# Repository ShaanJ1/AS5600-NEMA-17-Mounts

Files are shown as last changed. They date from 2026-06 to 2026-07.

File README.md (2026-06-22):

# AS5600 Nema 17 Mounts

Mounting hardware for attaching the AS5600 rotary encoder onto the back of the NEMA 17 stepper motor
Includes a magnet centering jig which helps you properly center the magnet onto the rear shaft to glue it in place

## Mounting Options:
### 1. Custom PCB + Spacers
Parts required:
- Diametric magnet
- Super glue (or equivalent strong adhesive)
- 4x M3 Machine Screws
- Custom AS5600 breakout board
- 4x Spacers

Installation Steps:

### 2. Custom mount for the AS5600
Parts Required:
- Diametric magnet
- Super glue (or equivalent strong adhesive)
- 3D printed sensor housing
- Regular AS5600 PCB
- 4x M2.5 screws

Installation Steps:

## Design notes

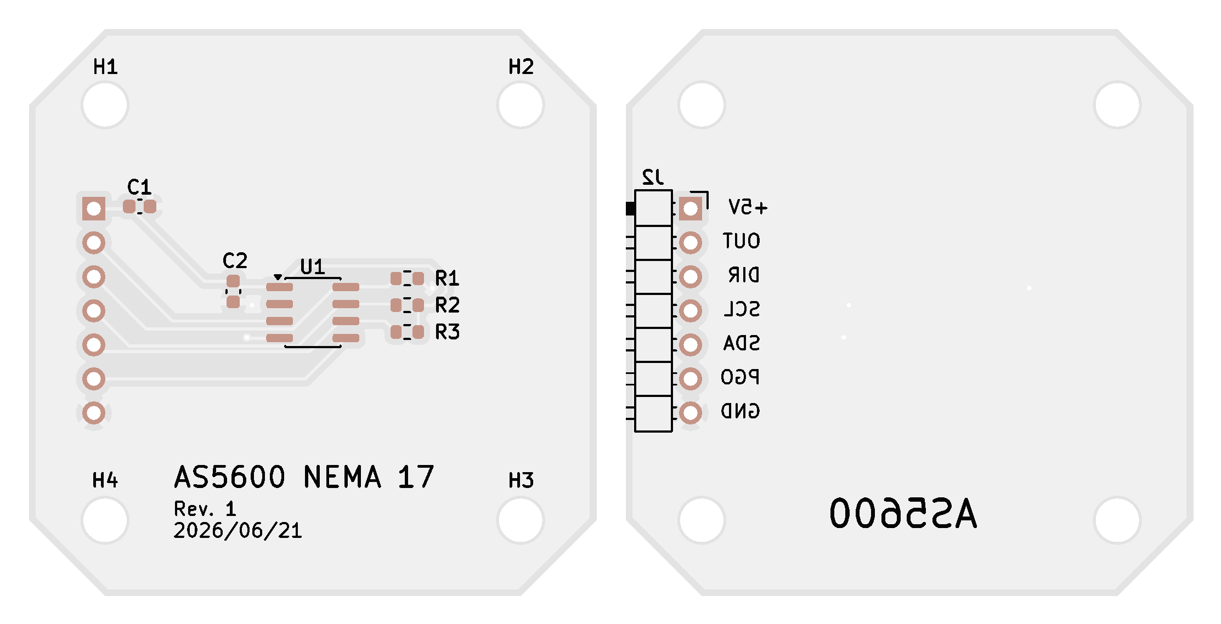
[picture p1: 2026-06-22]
pcb.png

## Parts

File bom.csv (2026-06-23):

Item Name/Purpose | Product Number | URL | Price | Quantity | Designator | Note
0.1uF 0603 Capacitor | C0603C104K3RACTU | https://www.digikey.ca/en/products/detail/kemet/C0603C104K3RACTU/416044 | $0.10 | 1 | C1
1uF 0603 Capacitor | C0603C105K4RACTU | https://www.digikey.ca/en/products/detail/kemet/C0603C105K4RACTU/2199788 | $0.10 | 1 | C2
2.54mm 1x7 Right Angled PinHeaders | PH1RB-07-UA | https://www.digikey.ca/en/products/detail/adam-tech/PH1RB-07-UA/9831064 | $0.20 | 1 | J2
AS5600 IC | AS5600-ASOT | https://www.digikey.ca/en/products/detail/ams-osram-usa-inc/AS5600-ASOT/4914338 | $3.19 | 1 | U1
10K 0603 Resistor | RC0603FR-0710KL | https://www.digikey.ca/en/products/detail/yageo/RC0603FR-0710KL/726880 | $0.10 | 1 | R1
4.7K 0603 Resistors | RG1608P-472-B-T5 | https://www.digikey.ca/en/products/detail/susumu/RG1608P-472-B-T5/1240593 | $0.20 | 2 | R2, R3
PCB |  | https://jlcpcb.com/ | $4.00 | 5 |  | MOQ: 5
M3 Machine Screws
Diametric Magnets |  | https://www.aliexpress.com/item/1005011549598859.html | $5.32 | 10 |  | Pack of 10
3D Printing |  |  | $15.00 | 1

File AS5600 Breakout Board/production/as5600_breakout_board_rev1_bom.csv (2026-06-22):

Designator | Footprint | Quantity | Value | LCSC Part #
C1 | 0603 | 1 | 0.1uF
C2 | 0603 | 1 | 1uF
J2 | PinHeader_1x07_P2.54mm_Horizontal | 1 | Conn_01x07
R1 | 0603 | 1 | 10K
R2, R3 | 0603 | 2 | 4.7K
U1 | SOIC-8_3.9x4.9mm_P1.27mm | 1 | AS5600

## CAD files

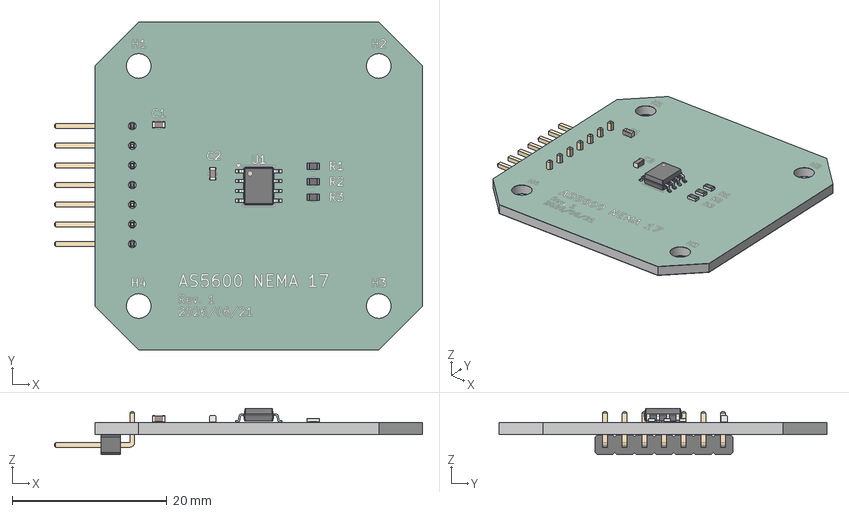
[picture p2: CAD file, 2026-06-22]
AS5600 Breakout Board/as5600 breakout board.step
47.5 x 42.3 x 5.97 mm
R_0603_1608Metric x 3
C_0603_1608Metric x 2
SOIC-8_3.9x4.9mm_P1.27mm
PinHeader_1x07_P2.54mm_Horizontal
as5600 breakout board_silkscreen x 2
as5600 breakout board_soldermask x 2
as5600 breakout board_PCB

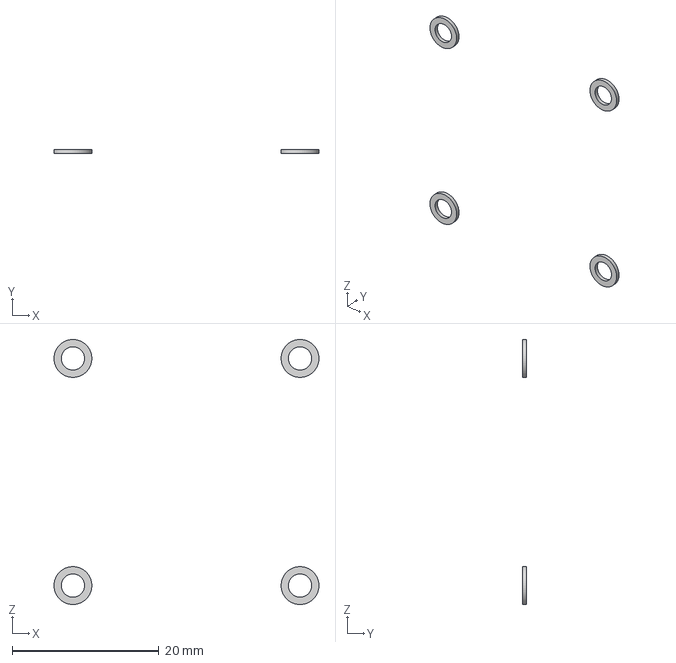
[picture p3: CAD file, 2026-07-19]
CAD/(4x) Spacers2.step
36.2 x 0.605 x 36.2 mm

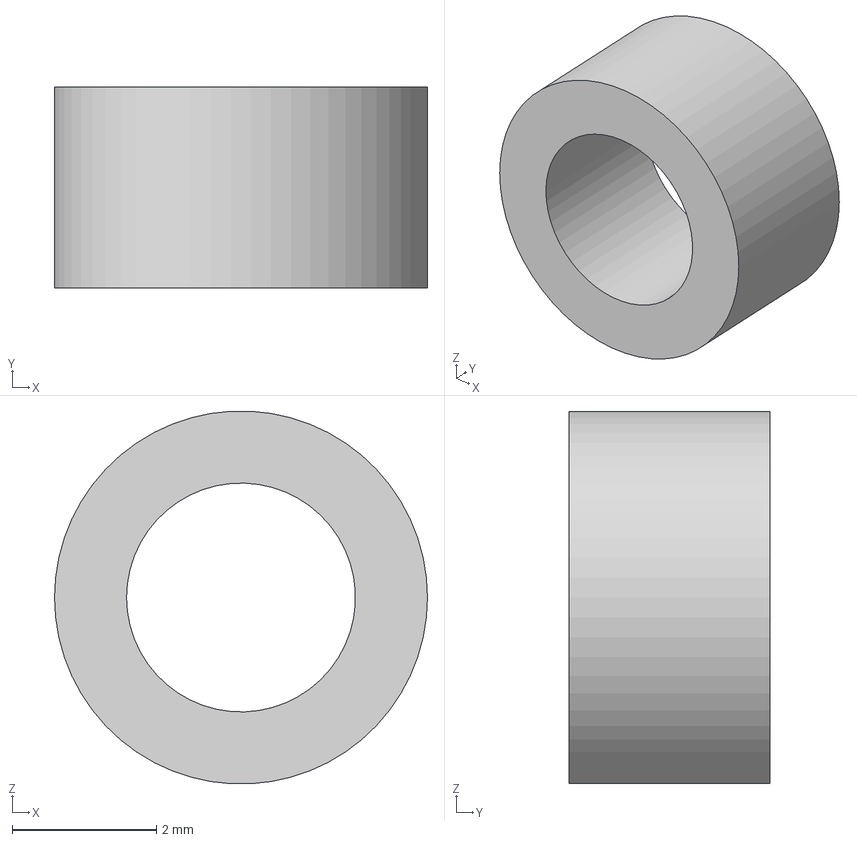
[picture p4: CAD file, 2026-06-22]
CAD/(4x) Spacer.step
5.17 x 2.79 x 5.17 mm

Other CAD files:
CAD/Mount.step
CAD/Holder2.step
CAD/Holder 5.step
CAD/Holder 6.step
CAD/Holder 3.step
CAD/Holder1.step
CAD/Holder 7.step
CAD/Sensor Mount.step
CAD/Holder 4.step

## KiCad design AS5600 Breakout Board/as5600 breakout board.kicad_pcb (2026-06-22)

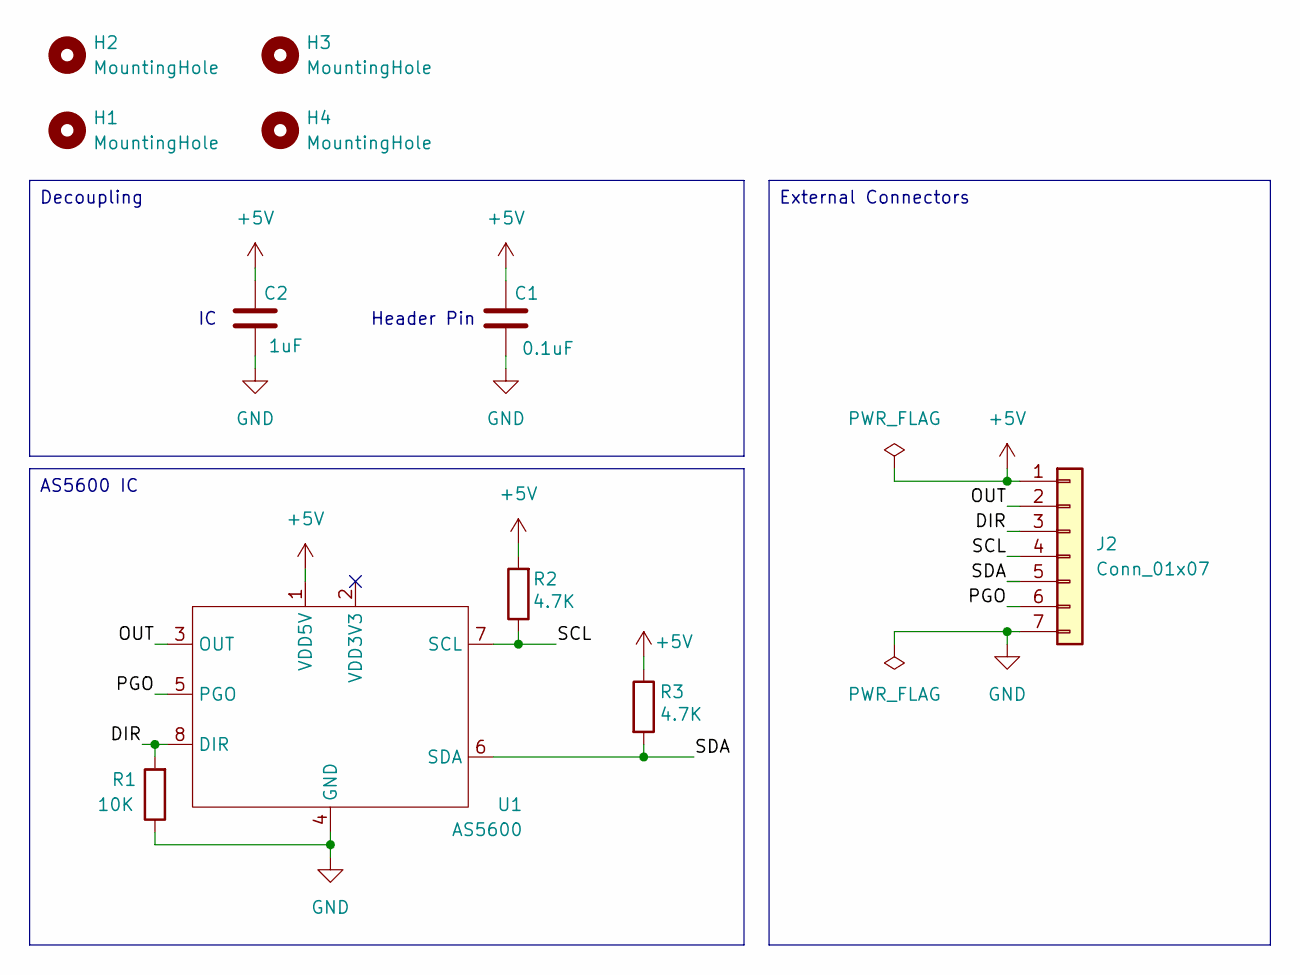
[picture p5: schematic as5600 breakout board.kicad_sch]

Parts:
C1: 0.1uF; C_0603_1608Metric
C2: 1uF; C_0603_1608Metric
H1, H2, H3, H4: MountingHole; MountingHole_3.2mm_M3
J2: Conn_01x07; PinHeader_1x07_P2.54mm_Horizontal
R1: 10K; R_0603_1608Metric
R2, R3: 4.7K; R_0603_1608Metric
U1: AS5600; SOIC-8_3.9x4.9mm_P1.27mm

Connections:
+5V: C1.1, C2.1, J2.1, R2.2, R3.1, U1.1 (VDD5V)
/DIR: J2.3, R1.2, U1.8 (DIR)
/OUT: J2.2, U1.3 (OUT)
/PGO: J2.6, U1.5 (PGO)
/SCL: J2.4, R2.1, U1.7 (SCL)
/SDA: J2.5, R3.2, U1.6 (SDA)
GND: C1.2, C2.2, J2.7, R1.1, U1.4 (GND)

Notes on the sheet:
Header Pin
Decoupling
External Connectors
AS5600 IC

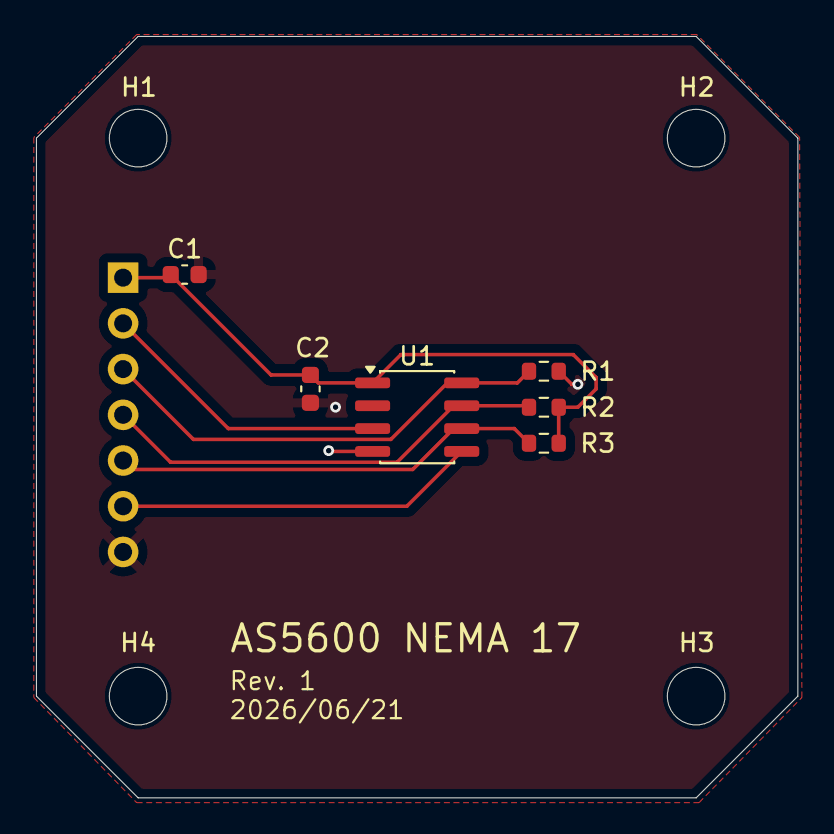
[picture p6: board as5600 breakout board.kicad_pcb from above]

Board: 2 copper layers, 42.3 x 42.3 mm, 11 parts (1 on the bottom side), 7 nets.

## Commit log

2026-06-22 Added project files
    [(4x) Spacer.step, Holder 3.step, Holder 4.step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]
2026-07-19 Updated CAD models for 45mm screw lengths
    [(4x) Spacers2.step, Mount.step]
